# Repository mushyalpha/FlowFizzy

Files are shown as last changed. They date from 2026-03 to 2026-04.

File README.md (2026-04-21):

# FlowFizzy Water Dispenser

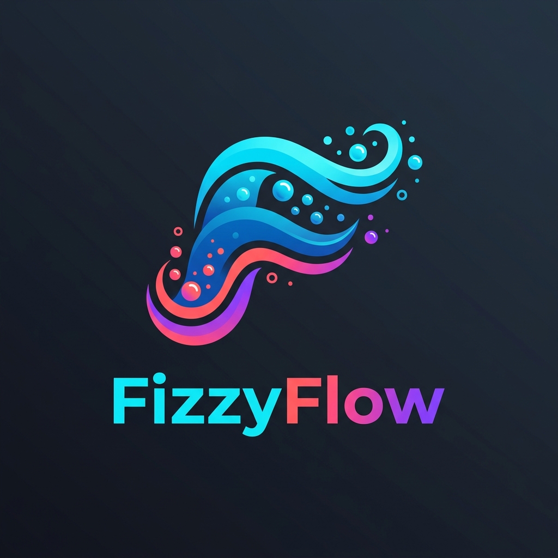
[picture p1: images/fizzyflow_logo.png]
FlowFizzy Logo


FlowFizzy is a smart, fully-automated touchless water dispenser built on the Raspberry Pi using C++. It utilizes intelligent hardware monitoring to safely dispense exact volumes of water using proximity detection.

For SOLID compliance, `FillingController` now depends on behavioral interfaces (`IProximitySensor`, `IPump`, `IFlowMeter`) instead of concrete drivers. We considered a template-based variant for zero-overhead static polymorphism, but chose runtime interfaces for clearer architecture and easier assessment traceability; at a 100 ms control interval, virtual dispatch overhead is negligible.

### [Watch the End-to-End Demo on YouTube](#) <!-- TODO: Add YT Link -->
### [Read our Project Tech Write-up on RS Design Spark](#) <!-- TODO: Add Blog Link -->
### [Follow us on Instagram](https://www.instagram.com/flow_fizzy/)

## Hardware Connections (Raspberry Pi Pinout)

Below is the definitive hardware wiring guide to connect the sensors and pump to the Raspberry Pi. For a visual representation, please refer to our physical circuit diagram:
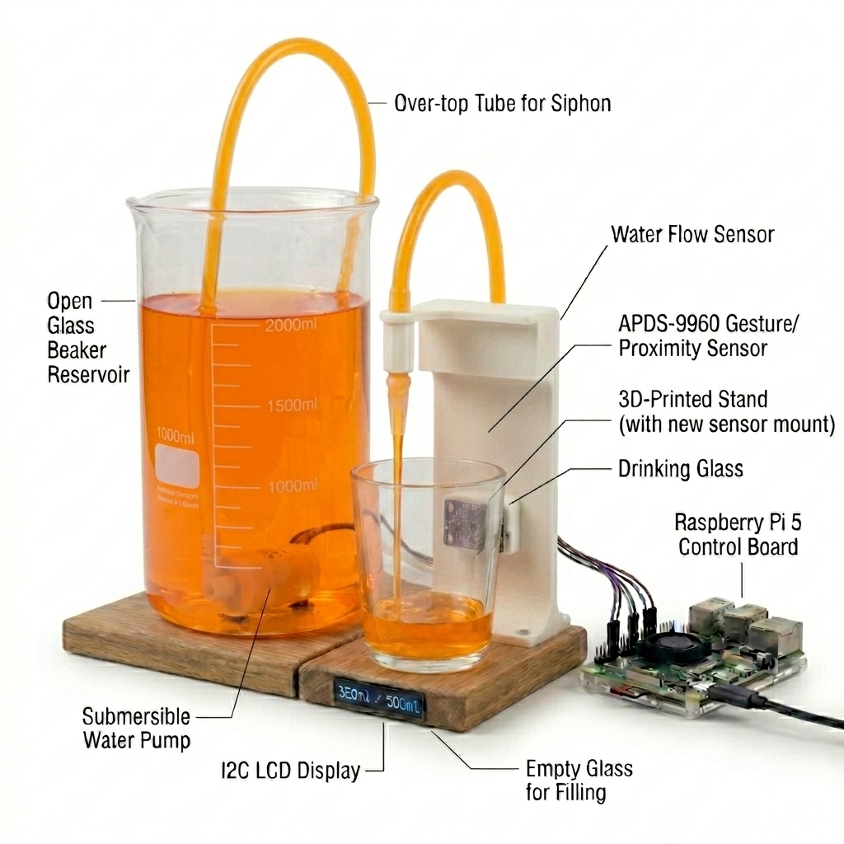
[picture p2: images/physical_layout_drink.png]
Drink Dispensing View


> **Note:** Always ensure the Raspberry Pi is powered OFF when altering hardware connections. 

### 1. Gesture/Proximity Sensor (DollaTek APDS-9960)
This acts as the touchless cup detector. It communicates via the I2C protocol natively over `3.3V`.
| Sensor Pin | Raspberry Pi Pin | Function |
| :--- | :--- | :--- |
| **VCC** | **Pin 1 (3.3V)** | Main Power |
| **GND** | **Pin 6 (GND)** | Ground |
| **SDA** | **Pin 3 (GPIO 2)** | I2C Data Line |
| **SCL** | **Pin 5 (GPIO 3)** | I2C Clock Line |
| **VL** | **Pin 17 (3.3V)** | Powers the IR LED for proximity |

### 2. Water Flow Sensor (YF-S401)
Sends digital pulses to precisely measure volume.
| Sensor Wire Color | Raspberry Pi Pin | Function |
| :--- | :--- | :--- |
| **Red** | **Pin 2 (5V)** | Power |
| **Black** | **Pin 9 (GND)** | Ground |
| **Yellow** | **Pin 11 (GPIO 17)** | Pulse Signal Line |

### 3. DC Submersible Pump (JT80SL via TIP122 Transistor)
Driven via a Darlington TIP122 with a flyback diode.
- **Base**: GPIO 18 (via 1k resistor)
- **Collector**: Pump Negative (-)
- **Emitter**: Ground (GND)
- **Diode**: Across Pump (+) and Collector.

---

## System Architecture

The system follows a strict event-driven, non-blocking architecture using `timerfd` and `libgpiod` interrupts. For full class and sequence diagrams, see our detailed [Architecture Documentation](docs/architecture.md).

```mermaid
graph TD
    A[Timer Worker] -->|timerfd 100ms| B[FillingController::tick]
    C[Gesture Worker] -->|timerfd 50ms| B
    D[Flow Worker] -->|GPIO Interrupt| E[Atomic Pulse Count]
    B -->|Atomic Read| E
    B -->|GPIO Write| F[Pump Controller]
    B -->|Callback| G[LCD Display]
```

### Real-Time Timing Requirements
| Requirement | Value | Mechanism |
| :--- | :--- | :--- |
| Gesture Poll Interval | 50 ms | `timerfd` (blocking) |
| State Machine Tick | 100 ms | `timerfd` (blocking) |
| Flow Interrupt Latency | < 1 ms | `libgpiod` Edge Events |
| Emergency Stop | < 150 ms | Proximity CLEARED → Pump OFF |

---

## Division of Labor
| Team Member | Primary Responsibilities |
| :--- | :--- |
| **Abdullah Alkabbawi** | Real-Time Architecture, State Machine Logic, Hardware Integration, Multithreading. |
| **Bonolo Masima** | Hardware Specifications, Documentation (ADRs), CAD Design, Integration Testing. |

---

## Bill of Materials (BoM)
| Item | Cost |
| :--- | :--- |
| DollaTek APDS-9960 Gesture Sensor | £4.99 |
| YF-S401 Water Flow Sensor | £7.45 |
| JT80SL DC Submersible Pump | £5.20 |
| TIP122 Transistor + Diode + Resistor Kit | £2.50 |
| 16x2 I2C LCD Display | £6.10 |
| Breadboard & Jumper Wires | £3.50 |
| Silicone Tubing (1m) | £2.00 |
| **TOTAL** | **£31.74 (Target: < £75)** |

---

## Build & Run Instructions

### 1. Fresh Raspberry Pi Installation
If you are starting from a completely blank Raspberry Pi OS (Bookworm or newer), follow these steps:
1. **Flash OS:** Flash Raspberry Pi OS (64-bit recommended) onto a MicroSD card using Raspberry Pi Imager. Ensure SSH and Wi-Fi are configured.
2. **Boot & Connect:** Insert the SD card, boot the Pi, and SSH into it.
3. **Enable I2C:** Run `sudo raspi-config` -> `Interfacing Options` -> `I2C` -> Enable.
4. **Clone the Repo:** `git clone https://github.com/mushyalpha/FlowFizzy.git && cd FlowFizzy`

### 2. Prerequisites
Run the following exactly as listed to install C++ compilers, CMake, and the standard GPIO driver library:
```bash
sudo apt-get update
sudo apt-get install -y cmake g++ libgpiod-dev libgpiod-doc
```

### 3. Build Instructions
```bash
mkdir build && cd build
cmake ..
make -j$(nproc)
```

### 4. Running Tests
You can automatically run all unit tests from the `build` directory:
```bash
# Run Google Test unit tests
make test
# OR manually run ctest to view verbose outputs:
ctest -V

# (Optional) Run hardware integration testing binaries:
sudo ./hardware_trio_test
```

### 5. Running the Application
```bash
sudo ./filling_machine
```

---

## Licensing
This project is licensed under the MIT License - see the [LICENSE](LICENSE) file for details.

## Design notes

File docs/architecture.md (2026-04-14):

# System Architecture

This document presents the overarching software design, sequence flows, and exact components mapping that define the AquaFlow touchless automated dispenser system.

---

## 1. Class Diagram

The following diagram demonstrates the core **SOLID** structural choices made for this system.
Note the heavy reliance on **Dependency Inversion (D)**: The `FillingController` acts only on abstractions (`IHardwareDevice` inputs mapped as concrete injected instances at run-time). It is completely unaware of Linux/GPIO specifics.

```mermaid
classDiagram
    class IHardwareDevice {
        <<interface>>
        +init() bool
        +shutdown() void
    }

    class FlowMeter {
        -atomic~int~ pulseCount_
        -thread edgeThread_
        +getPulseCount() int
        +getVolumeML() double
        +hasReachedTarget(double) bool
    }

    class PumpController {
        -bool running_
        -int pumpPin_
        +turnOn() void
        +turnOff() void
        +isRunning() bool
    }

    class GestureSensor {
        -int i2cAddr_
        -timerFd_
        +registerEventCallback(cb) void
    }

    class FillingController {
        -SystemState state_
        -double targetVolumeML_
        +tick() void
        +registerMonitor(cb) void
    }

    class Monitor {
        +onStateChange(string, double, int)
    }

    class LcdDisplay {
        +printStatus(string, double, int)
    }

    IHardwareDevice <|-- FlowMeter
    IHardwareDevice <|-- PumpController
    IHardwareDevice <|-- GestureSensor
    IHardwareDevice <|-- LcdDisplay
    
    FillingController --> GestureSensor : uses
    FillingController --> PumpController : uses
    FillingController --> FlowMeter : uses
    
    Monitor ..> FillingController : observer
    LcdDisplay ..> Monitor : bound callback
```

---

## 2. Sequence Diagram

This sequence traces the primary temporal flow of operations: From the user placing their cup, through proximity callbacks and flow counting, closing off back to an idle state.

```mermaid
sequenceDiagram
    actor User
    participant GS as Gesture Sensor (Thread)
    participant FC as FillingController
    participant T as Timer (Main Tick)
    participant P as PumpController
    participant FM as FlowMeter (Thread)
    participant L as LcdDisplay
    
    User->>GS: Place cup near sensor
    activate GS
    GS-->>FC: Proximity Triggered Event (Store Atomic=True)
    deactivate GS
    
    loop Every 100ms
        T->>FC: tick()
        FC->>FC: STATE: WAITING -> CONFIRMATION
    end
    
    note over FC,T: Cup held for Hold Time (e.g. 2s)
    
    T->>FC: tick() (hold time complete)
    FC->>FM: resetCount()
    FC->>P: turnOn()
    FC->>FC: STATE: CONFIRMATION -> FILLING
    FC-->>L: Update Dislay (Filling)
    
    loop Real-Time Flow Monitoring
        FM->>FM: Hardware Pulses increment Volume (Async)
        T->>FC: tick()
        FC->>FM: hasReachedTarget(volume) -> False
        FC-->>L: Update Volume Dispensed
    end
    
    note over FM: Target Volume Reached
    T->>FC: tick()
    FC->>FM: hasReachedTarget(volume) -> True
    FC->>P: turnOff()
    FC->>FC: STATE: FILLING -> FILL_COMPLETE
    FC-->>L: Update Display (Done)
    
    User->>GS: Removes Cup
    GS-->>FC: Proximity Cleared Event
    
    T->>FC: tick()
    FC->>FM: resetCount()
    FC->>FC: STATE: FILL_COMPLETE -> WAITING
```

---

## 3. Physical Software Mapping Architecture

This diagram demonstrates how hardware interfaces directly communicate natively with our encapsulated classes to form the whole package.

```mermaid
graph TD
    subgraph Physical Hardware
        APDS9960[APDS-9960 Gesture/Prox]
        YFS[YF-S401 Flow Meter]
        PumpEngine[JT80SL Pump + TIP122]
        LCD[16x2 I2C LCD Display]
    end

    subgraph Hardware Abstraction Layer
        GS_Class[GestureSensor]
        FM_Class[FlowMeter]
        Pump_Class[PumpController]
        LCD_Class[LcdDisplay]
    end

    subgraph OS Protocols
        I2C1[I2C Bus 1]
        GPIO_Edge[libgpiod Edge Events]
        GPIO_Out[libgpiod Digital Output]
    end

    APDS9960 -->|I2C 3.3v| I2C1
    I2C1 --> GS_Class

    YFS -->|Pulses 5v| GPIO_Edge
    GPIO_Edge --> FM_Class

    Pump_Class --> GPIO_Out
    GPIO_Out -->|Digital High 3.3v| PumpEngine

    LCD_Class --> I2C1
    I2C1 -->|Commands| LCD
```

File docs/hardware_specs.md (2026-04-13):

# Hardware Specifications

A reference document for the various hardware components used in the AquaFlow project.

---

## Pump: JT80SL DC Submersible Mini Water Pump
- **Electrical:**
  - Voltage: DC 2.5–6V
  - Current: 130–220 mA
  - Power: 0.4–1.5W
- **Performance:**
  - Flow rate: 80–120 L/H
  - Max head (hydraulic lift): 40–110 cm
- **Physical:**
  - Length: 56 mm (including water inlet)
  - Height: 33 mm (including water outlet)
  - Diameter: 24 mm
  - Weight: 30 g
  - Water inlet/outlet inner diameter: 4.5 mm (both)
  - Water inlet outer diameter: 6.8 mm
  - Water outlet outer diameter: 7 mm
- **Operating Notes:**
  - Submersible only - not self-priming; water level must be above the pump at all times.
  - Running dry causes overheating and noise.
  - Rotor can clog; clean regularly if water quality is low.

---

## Sensor: YF-S401 Hall Effect Water Flow Sensor
- **Electrical:**
  - Operating voltage: DC 5V–18V (datasheet min: 3.5V, practically works at 3.3V per field reports)
  - Max current draw: 15 mA (at DC 5V)
  - Signal output: Square wave pulse (Hall effect, open collector)
- **Performance:**
  - Flow range: 0.3–6 L/min
  - Pulse rate: ~5880 pulses/litre (~0.17 mL per pulse)
  - Max water pressure: 1.75 MPa
- **Physical:**
  - Dimensions: 58 × 35 × 27 mm
  - Weight: 25 g
  - Connection: G1/4" fitting, compatible with 5–7 mm ID hose (6 mm optimal)
  - Included: 30 cm silicone tubing (6 mm ID)
- **Wiring (3-wire):**
  - Red: VCC (5V)
  - Black: GND
  - Yellow: Signal (pulse output)
- **Operating Notes:**
  - Hall effect sensor is sealed from the water path - stays dry.
  - Not self-priming; designed for inline use in an active flow path.
  - Clean water only; avoid chemical exposure and physical shock.

---

## Gesture Sensor: DollaTek APDS-9960
- **Features:** Sensor for ambient light, RGB detection, proximity, gesture, and motion recognition.
- **Brand:** DollaTek
- **Power:** Corded Electric; operates at 3.3 V 
- **Weight:** 0.08 kg
- **Interaction:**
  - Detects ambient light and RGB colors accurately.
  - Recognizes gestures: Up, Down, Left, Right.
  - Detection range: 100–200mm. 
- **Hardware Integration:**
  - Communicates via I2C interface.
  - Features infrared LED, proximity sensor.
  - Pins: VCC/GND (3.3 V power), SDA/SCL (I2C), INT (interrupt), VL (infrared LED power).
  - Board size: 15.5 x 20.5 mm.

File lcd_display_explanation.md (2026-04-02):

# LcdDisplay Code Explanation

This document explains the functionality of the `LcdDisplay` component in the AquaFlow project, specifically focusing on `LcdDisplay.h` and `LcdDisplay.cpp`.

## Overview
The `LcdDisplay` class is a hardware driver for a **Freenove I2C LCD 1602** display (16 columns, 2 rows). It controls an underlying HD44780 LCD controller attached via a PCF8574T I2C backpack. This setup allows the Raspberry Pi to control the full display using only **4 wires** (5V power, Ground, SDA data, and SCK clock) over the I2C interface.

The class implements the `IHardwareDevice` interface, ensuring it integrates cleanly and identically to other hardware components in the system like the `PumpController` and `FlowMeter`.

## Key Features

1. **Direct POSIX I2C Communication**: 
   The code uses the standard Linux kernel I2C interface (`/dev/i2c-N` and `ioctl()`) to communicate directly with the device. This is a very clean approach because it avoids pulling in bulky third-party libraries (like WiringPi), relying entirely on standard C++ POSIX functions.

2. **Flicker-Free Text Updating**: 
   A common issue with basic LCD code is that clearing the screen before printing new text causes a visible, annoying "flicker". This driver solves that in the `print()` method by intelligently padding every string with spaces so it is exactly 16 characters long. This perfectly overwrites the previous text without ever needing to clear the screen!

## Core Methods

### `init()`
- Opens the `/dev/i2c-N` file corresponding to the configured bus number to establish the connection.
- Executes the highly specific initialization sequence required by the HD44780 datasheet: sending pulses and waiting exact microsecond delays to put the display into "4-bit mode".
- Configures the display for 2 lines and 5x8 dot characters.
- Turns on the display, turns on the backlight, clears the screen, and sets the cursor to automatically advance to the right.

### `shutdown()`
- Safely and cleanly powers down the display.
- Clears the screen and prints a farewell message: `AquaFlow \ Shutting down...`.
- Waits 1.5 seconds so the user can read the message, then dynamically cuts power to the backlight and closes the Linux file descriptor.

### `print(int row, const std::string& text)`
- Utility method to write text to either the top row (`0`) or bottom row (`1`).
- Manipulates the string to be precisely 16 characters long.

### `showVolume(double volumeML)`
- Formats the current dispensed liquid volume into a readable string (e.g., `Vol: 123.4 ml`).
- Specifically updates the bottom row (row 1). This is meant to be called rapidly (e.g. 1Hz timer) while the machine is actively filling a bottle.

### `showStatus(const std::string& state, double volumeML, int bottles)`
- High-level method called by the main system whenever the machine changes states (e.g., from `IDLE` to `FILLING`).
- **Row 0**: Writes the current system state (e.g. `FILLING`). It has a smart optimization where it skips writing if the state hasn't changed, saving processing and I2C bandwidth!
- **Row 1**: Contextually decides what to show. If it's `FILLING`, it shows the live volume. If the machine is resting (`IDLE`, `DONE`, `WAITING`), it displays the total count of bottles dispensed so far.

## Low-Level Hardware Interface (The bottom half)
The bottom portion of the code (`send`, `write4bits`, `pulseEnable`, etc.) handles the grueling electronics protocol required for the backpack chip:
- Because the I2C chip only has 8 pins, and the LCD requires more, the driver uses "4-bit mode". It splits every byte of data into two 4-bit chunks ("nibbles") and sends them one after the other.
- The `pulseEnable()` function accurately toggles the LCD's `En` (Enable) pin HIGH then LOW in the span of exactly 51 microseconds, effectively telling the chip "LATCH THIS DATA NOW".
- The `expanderWrite()` function always intelligently ORs your data with the backlight bit. This ensures that every time you send data, the code doesn't accidentally turn off the backlight.

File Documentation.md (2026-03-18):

# Smart Flow - Automated Water Dispenser

**Components:** Water Pump | YF-S401 Flow Meter | HC-SR04 Ultrasonic Sensor

---

| Field | Details |
| --- | --- |
| **Project Title**  | Smart Flow - Automated Water Dispenser |
| **Platform** | Raspberry Pi 5 using C++ |
| **Core Mechanism** | Manual bottle placement → detect & stabilise → fill to target → remove |
| **Key Sensors** | YF-S401 flow meter + HC-SR04 ultrasonic sensor |
| **Control Logic**  | Real time state machine (20ms loop) |

---

## 1. Summary

This project implements a real time Automated Water Dispenser on a Raspberry Pi 5 using C++. The system detects when a user places a bottle or a glass under the nozzle using an ultrasonic sensor, waits for the reading to stabilise (to ignore passing hands), fills the bottle to a precise target volume using a flow meter, and stops. The entire process is controlled by a hard real-time state machine running at a 20ms loop.

> **Hard real-time consequence of missing a deadline:** At a flow rate of ~400 ml/min, the pump dispenses ~6.6 ml/sec. If the pump-stop ISR is delayed by more than 5 ms, the bottle or glass overfills.

---

## 2. Problem Statement

Manual water bottling is slow and inconsistent in fill volume. This project demonstrates how an automated water dispenser can be built using an affordable single board computer and real-time C++, achieving high fill accuracy.

The core engineering challenges are:
1. Detecting a bottle or glass reliably with an ultrasonic sensor, filtering out spurious signals (like a hand moving past).
2. Monitoring the rising water surface with the same ultrasonic sensor to stop filling before the glass overflows.
3. Measuring dispensed volume accurately using pulse counting from a flow meter.
4. Ensuring the pump stops at exactly the right moment to hit the target volume.
5. Coordinating the sensors and pump as a single real-time system with no timing errors.

### The Complete Filling Cycle

| Step | Action |
| ---- | --- |
| **Step 1: IDLE** | System waiting, pump off. |
| **Step 2: DETECTED**  | Ultrasonic sensor detects object at correct distance. |
| **Step 3: STABILISE** | System waits briefly to confirm it is a bottle, not a hand. |
| **Step 4: FILLING** | Pump on, flow meter counting pulses. |
| **Step 5: COMPLETE**  | Ultrasonic detects water surface near top, or pulse count hits target. Pump stops. |
| **Step 6: REMOVE** | User removes filled bottle. System returns to Step 1. |

---

## 3. System Architecture

### 3.1 Physical Layout

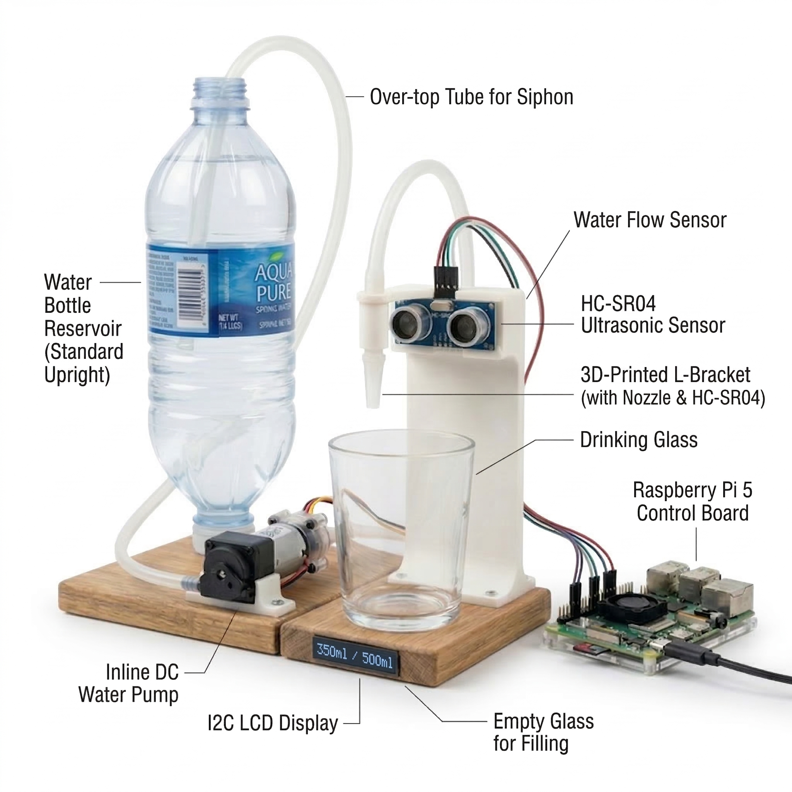
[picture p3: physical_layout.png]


### 3.2 State Machine Diagram

```mermaid
stateDiagram-v2
    [*] --> IDLE
    IDLE --> STABILISING : bottle or glass detected
    STABILIZING --> FILLING : Stable for a few ms
    
    state FILLING {
        [*] --> Pump_ON
        Pump_ON --> Read_Flow_Sensor
        Read_Flow_Sensor --> Update_LCD
        Update_LCD --> Read_Flow_Sensor : Loop while filling
    }
    
    FILLING --> FILL_COMPLETE : Flow >= Target
    FILL_COMPLETE --> IDLE : Bottle Removed
```

---

## 4. Software Architecture: Class Design (SOLID Principles)

All Raspberry Pi code is written in C++ following SOLID design principles. Each hardware component is contained in its own class with a well defined public interface. All internal data is private, and classes communicate exclusively through callbacks and setters, never through shared global state. Dynamic resources are managed via RAII and `std::shared_ptr`; there are no raw `new`/`delete` calls or void pointers in application code.

| Class | Responsibility |
| --- | --- |
| `WaterPump` | Wraps relay GPIO; controls pump power via `on()`/`off()` setters |
| `FlowMeter` | Owns pulse ISR thread; converts pulses to ml; exposes `std::function` callback on each pulse |
| `UltrasonicSensor` | Manages trigger/echo pins; measures distance to bottle and rising water surface; exposes callback with distance reading |
| `FillingStateMachine` | Orchestrates state transitions; subscribes to sensor callbacks; calls pump setters |
| `MonitorThread` | Normal-priority thread: LCD, MQTT, CSV log |

### 4.1 Event-Driven Callback Flow

The system is fully event-driven following the blocking I/O + thread wakeup pattern taught in the course. There are no polling loops or sleep based timing anywhere in the application.

---

---

**How each thread works:**

1. **FlowMeter thread** (priority 90): uses `libgpiod` `wait_edge_events()` as blocking I/O. The thread sleeps until a rising edge arrives from the YF-S401 Hall sensor, then increments the pulse counter and fires the callback. No CPU is consumed while waiting.
2. **UltrasonicSensor thread** (priority 80): triggers a 10us pulse on the trigger pin, then blocks on the echo pin edge event via `libgpiod`. The time between rising and falling edge gives distance. Fires callback with the result.
3. **FillingStateMachine** (priority 80): runs on a 20ms periodic loop using `clock_nanosleep`. Each iteration reads the latest sensor values delivered by callbacks and evaluates state transitions.
4. **MonitorThread** (normal priority): a non-real-time thread that updates the LCD, publishes MQTT telemetry, and writes CSV logs. It is never in the critical path.
5. **Main program**: after constructing all objects and registering callbacks via lambda functions, the main thread blocks (e.g. `getchar()`) and does no further work until shutdown.

---

## 5. Real-Time Latency Budget

All timing decisions are derived from measured or calculated worst-case latencies.

| Event | Latency Target | Consequence of Miss | Mechanism |
| --- | --- | --- | --- |
| Flow meter pulse ISR response | < 1 ms | Pulse lost, volume miscounted | `SCHED_FIFO` 90 ISR thread (highest priority) |
| Pump stop at target volume | < 2 ms | Overfill by ~16 ml per ms of delay | ISR directly writes GPIO via `stop()` |
| LCD / MQTT update | < 500 ms | No user-visible impact | Normal-priority `MonitorThread` (non-RT) |
| State machine loop period | 20 ms | Delayed response to sensor events  | `SCHED_FIFO`, `clock_nanosleep` periodic wake |

**Why `SCHED_FIFO` priority 80?** This places the control loop above standard Linux processes (priority 0 to 20) while reserving priority 99 for kernel interrupt threads and priority 90 for the pulse ISR, ensuring the flow meter ISR always pre-empts the state machine rather than the reverse.

---

## 6. GUI and Data Visualisation

A Qt 6 GUI runs on the Raspberry Pi and provides real-time plotting of the dispensing process. The GUI is refreshed via a Qt timer (screen refresh only, not used for real-time timing) while actual sensor data arrives through the callback architecture described above.

| Widget | Purpose |
| --- | --- |
| QCustomPlot graph | Live plot of flow rate (ml/s) and fill level over time |
| Volume label | Current dispensed volume in ml |
| Target spinbox | Allows the user to set a custom fill target via mouse/keyboard |
| Reset button | Clears the current fill and returns to IDLE |

The GUI thread is started last in `main()` with `app.exec()`, which blocks. All real-time threads are started before the GUI. Qt timers are used only for screen refresh (~40 ms interval) and are never used for sensor timing.

**Prerequisites for GUI:**

```
sudo apt-get install qt6-base-dev libqcustomplot-dev
```

---

## 7. Hardware Components

| Component | Purpose |
| --- | --- |
| Raspberry Pi 5 | Main real-time controller |
| 12V Water Pump | Drives water flow from tank to nozzle |
| 5V 1-Channel Relay (Opto-isolated) | Switches the 12V pump on and off via GPIO |
| YF-S401 Flow Meter | Measures fill volume in ml (low flow) |
| HC-SR04 Ultrasonic Sensor + Clamp  | Detects bottle presence and monitors rising water level |
| 16x2 LCD (I2C) | State and fill volume display |
| Active Buzzer | Fill complete audio feedback |
| 1N4007 Diode | Flyback protection on pump relay |

---

## 8. Build and Run

### Prerequisites

```bash
sudo apt-get install cmake g++ libgpiod-dev qt6-base-dev libqcustomplot-dev libi2c-dev
```

### Build

```bash
cmake .
make
```

### Run

```bash
sudo ./smart_flow
```

`sudo` is required for GPIO access and `SCHED_FIFO` thread scheduling.

### Unit Tests

```bash
make test
```

Unit tests verify:
- Flow meter pulse-to-ml conversion accuracy
- Ultrasonic sensor distance calculation
- State machine transitions (IDLE to STABILISE to FILLING to COMPLETE)
- Pump GPIO on/off sequencing

---

## 9. Division of Labour

| Member | Primary Responsibility |
| --- | --- |
| Chandan and Radha | Hardware assembly: mechanical build, wiring, hardware sourcing |
| Bonolo and Abody  | Real time software: state machine, ISR handlers, SCHED_FIFO threading |
| Bonolo, Abody, Radha | Sensor integration: flow meter calibration, ultrasonic sensor tuning |
| Mena | Monitoring and data: LCD driver, MQTT dashboard, CSV logging |
| Mena and Radha | Testing, documentation and presentation: unit tests, GitHub Pages |

---

## 10. License

This project is licensed under the MIT License.

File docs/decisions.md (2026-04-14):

# Architecture & Technical Decisions (ADRs)

A master log of technical bottlenecks and the resolutions implemented for the AquaFlow project.

---

## [CLOSED] Decision 1: Pump vs Solenoid Valve
- **Problem:** The original setup utilised a 12V Solenoid valve. It looked solid and we bought a relay for it, but ultimately we couldn't get it working with our setup and it made the footprint too bulky.
- **Resolution:** Reverted to a DC submersible pump (JT80SL) instead of the solenoid valve.

## Decision 2: Managing Pump Power Draw
- **Problem:** The JT80SL draws up to 220mA, which is > 10x what a single Raspberry Pi GPIO pin can safely handle (16 mA max). 
- **Resolution:** We cannot connect it directly. Instead of using 3x 1.5v AA batteries, we wired a **T1P121 transistor with a flyback diode and a 1000 ohm resistor**. (Note: Consider switching to a MOSFET in the future).
- *Open Concern:* We need to establish if the concern about the 5V pin being over-occupied is a real concern and how to solve it.

## Decision 3: Resolving 5V Rail Contention
- **Problem:** We have 2 sensors, a pump, and LCDs, and they are all competing for the Pi's 5V rail. We used a relay module for the pump that took up two 5V pins.
- **Resolution Plan:** The pump should ideally be powered from a separate 5V supply rather than directly from the Pi. This avoids startup current spikes that can drop voltage and destabilise the Pi. Pi GPIO should only be used for control.
- **Proposed setup:** 
  - External 5V supply for pump.
  - Relay or MOSFET for switching.
  - Common ground shared with Raspberry Pi.
  *(Note: We already have a 12V power supply and can use an LM2596 Buck Converter).*

## Decision 10: Fluid Dynamics & Tubing Layout

- **Context:** We have 1m of 6mm tubing and need to determine the optimal configuration for connecting the submersible pump, the YF-S401 water flow sensor, and the dispensing nozzle.
- **Decision:** **Use the shortest possible tubing run. The pump must be submerged, with the flow sensor placed inline after the pump.**
- **Rationale for Tubing Length (Shorter is Better):**
  - **Priming Latency:** A longer tube holds more air when empty, causing a noticeable delay before water reaches the cup when the pump starts. Shorter tubes mean a snappier, more responsive system.
  - **Head Loss:** Longer tubes create more flow friction, putting unnecessary strain on our small 5V DC pump and reducing the maximum flow rate.
  - **After-Drip:** A long tube acts as a reservoir. Once the pump cuts off, any water remaining in the tube will slowly drip out, which completely ruins the precision of our calibrated dispensing volumes.
- **Rationale for Component Positioning:**
  - **Pump Submersion:** The JT80SL is a *submersible* pump. Because it draws water through a slotted casing rather than an inlet port, there is no way around it: it **must** sit fully submerged at the bottom of the water source/reservoir.
  - **Flow Sensor Placement:** The flow sensor must be placed on the pressure-side (attached directly to the tubing coming *out* of the pump). It requires positive, pressurized flow to spin its internal hall-effect turbine accurately. 
  - **Proximity:** Keep the flow sensor relatively close to the pump but try to allow a straight run of tubing leading into it. Minimizing curves right before the sensor reduces turbulent water flow, leading to much more stable and predictable pulse readings.

---

## Decision 4: Hardware Scope - Keep Current Design, Do Not Expand

- **Context:** Proposal raised to extend the hardware (viscosity sensing, restoring the ultrasonic sensor). The counter-argument is that expanding hardware scope at this stage risks diverting time away from code quality - the primary marking criterion.
- **Decision:** **Freeze the hardware at its current scope.** The system already fulfils its core function (touchless cup detection → pump → precise volume dispensing) and does so well. Adding components for novelty at this stage would provide diminishing returns.
- **Rationale:**
  - The assessment is marked predominantly on code quality (SOLID, encapsulation, real-time architecture, revision control, documentation). Hardware is not a graded criterion on its own.
  - The novelty angle was assessed at the presentation stage, which has already passed.
  - Bringing back the ultrasonic sensor is redundant - the APDS-9960 gesture sensor handles proximity detection and is already integrated. Running both in parallel would add complexity with no functional benefit.
  - Time is better invested in: unit tests, documentation, UML diagrams, and commit quality - all of which directly affect the final grade.

---

## Decision 5: Pump Power Supply - Evaluate Powerbank Integration

- **Context:** Current setup drives the pump via a TIP122 transistor + flyback diode from the Pi's 5V rail. A portable powerbank is available that could act as a dedicated external supply.
- **Decision:** **Conditionally adopt the powerbank if integration is non-invasive.** If it can be wired as a simple external 5V supply (common ground with Pi, pump powered via powerbank, transistor control signal still from GPIO) without requiring a redesign of the existing circuit, it is worth adopting.
- **Rationale:**
  - A dedicated supply eliminates current spikes on the Pi's 5V rail, reducing the risk of the Pi browning out mid-dispense.
  - The transistor switching circuit (base resistor + flyback diode) remains unchanged - only the supply rail moves.
  - If it requires more than 30 minutes of hardware rework, defer. Code quality is the priority.
- **Open action:** Wire powerbank → collector side of TIP122; verify common ground with Pi. Test pump performance under load.

---

## Decision 6: Volume Measurement - Retain Flow Meter, Improve Calibration

- **Context:** Proposal to replace the YF-S401 flow meter with a load cell for more accurate volume measurement. The flow meter required field calibration against a beaker.
- **Decision:** **Retain the YF-S401 flow meter.** Recalibrate using a more accurate volumetric flask if precision is still insufficient.
- **Rationale:**
  - Replacing the flow meter with a load cell would require a new hardware driver class, new calibration, and re-integration with `FillingController` - a significant diversion of time.
  - The flow meter's event-driven pulse counting is already a strong RTES demonstration (GPIO interrupt → `atomic<int>` → callback). A load cell would likely require polling an ADC, which is architecturally weaker for this course.
  - The current calibration (`0.073774 ml/pulse`, derived from 2711 pulses for 200 ml) is documented and reproducible. A more accurate flask would tighten this without touching code.
  - A load cell is only justified if the flow meter's accuracy is proven to be a functional problem during the demo. Until then, it is not worth the risk.

---

## Decision 7: Gesture Sensor - Improve C++ Implementation, Do Not Switch Libraries

- **Context:** Gesture direction detection (swipe UP/DOWN/LEFT/RIGHT) works reliably in Python but produces unreliable results in C++. Proximity detection works well in both. Proposal raised to port the Python library logic to C++.
- **Decision:** **Improve the existing C++ FIFO parsing implementation.** The full APDS-9960 register-level documentation is available; the Python library is open-source and can be used as a reference for the algorithm, not as a dependency.
- **Rationale:**
  - The Python library (e.g., `adafruit-circuitpython-apds9960`) is not a C++ dependency and cannot be called directly. "Converting" it means reading its gesture-decoding logic and reimplementing it in C++ - which is exactly what our current `GestureSensor.cpp` does.
  - The likely cause of the discrepancy is the FIFO read timing. Python libraries typically add small delays between FIFO reads to allow the gesture engine to settle; our C++ implementation polls the FIFO on a 50 ms timerfd tick which may be too coarse or too fast for certain swipe speeds.
  - **Fix approach:** Compare the Python library's gesture-decoding thresholds and FIFO drain strategy against our current implementation. Tune `POLL_INTERVAL_MS`, gesture entry/exit thresholds (`GPENTH`/`GEXTH`), and the minimum-frame filter (`gesture_dataset_count_ > 4`).
  - If gestures are improved, this becomes a strong novelty differentiator for the demo. If they remain unreliable, proximity-only mode (cup detection) is sufficient for the core dispensing function.
- **On the ultrasonic sensor suggestion:** Rejected. An ultrasonic sensor cannot detect gesture direction and would only replicate the proximity function already handled by the APDS-9960.

---

## Decision 8: Project Complexity - Sufficient for Assessment Purposes

- **Context:** Concern raised that the project may be too simple from a hardware perspective relative to other teams.
- **Decision:** **Scope is adequate; shift focus to code depth and documentation quality.**
- **Rationale:**
  - Complexity in this course is judged on the *code*, not the number of hardware components. A simple hardware setup with excellent SOLID architecture, event-driven threading, comprehensive unit tests, and clean documentation will outperform a complex hardware setup with poor code quality.
  - AquaFlow already demonstrates: multi-threaded event-driven architecture (`GestureSensor` + `FlowMeter` + `Timer` each on independent worker threads), a proper state machine (`FillingController`), RAII memory management, and `libgpiod` v2 GPIO - all of which are exactly what the marking rubric rewards.
  - If gesture detection is polished and working for the demo, that alone is a compelling novelty angle that requires no additional hardware.

---

## Decision 9: Final Form Factor - Prototype HAT / Stripboard vs Custom PCB

- **Context:** The current breadboard prototype is messy with loose wires. A proposal was made to design and order a custom PCB for a cleaner final product. However, there is concern about the time investment required.
- **Decision:** **Migrate to a solderable Stripboard or Raspberry Pi Prototype HAT instead of a custom PCB.**
- **Rationale:**
  - Standard PCB fabrication and shipping lead times (e.g., JLCPCB) take 1-2 weeks, which introduces massive timeline risk if the board is delayed or requires a second revision.
  - Designing a PCB in KiCad diverts significant time away from code architecture, testing, and documentation - all of which carry heavy weight in the assessment marking criteria.
  - A simple perfboard, stripboard, or Pi Prototype HAT achieves the exact same goal (eliminating loose breadboard jumper wires, creating a robust physical unit for demo day) but can be soldered together in a single afternoon using standard lab equipment.
  - The circuit is incredibly simple (one TIP122, a diode, a single resistor, and standard female header pins for the sensors) making a full custom PCB functionally overkill.

---

## Decision 11: Route Hardware Output through Logger (SRP Enforcement)

- **Context:** The `PumpController` class used explicit `std::cout` and `std::cerr` calls for debugging and status updates (e.g., pump initialization, start/stop events).
- **Decision:** **Substitute `std::cout/cerr` with `Logger::info()/error()` within all hardware driver classes (starting with `PumpController`).**
- **Rationale:**
  - **Single Responsibility Principle (SRP):** A hardware driver class should purely manage the hardware (e.g., pulling a GPIO pin high/low). Handling user presentation, including console output formatting, violates SRP because it gives the class two reasons to change: 1) if the hardware swaps, or 2) if logging/UI needs alteration.
  - By routing messages through the `Logger` component, `PumpController` delegates the responsibility of formatting, routing, and thread-safety of logs back to a centralized utility designed for that purpose.

---

## Decision 12: Architectural Principles & Multithreading (SOLID)

- **Context:** Deciding the software constraints and architecture map mapping logic state to hardware feedback.
- **Decision:** **Strictly enforce SOLID principles specifically Dependency Inversion (D), Liskov Substitution (L), and Open-Closed Principle (O) alongside an asynchronous event-driven layout.**
- **Rationale & Applied Implementations:**
  1. **Dependency Inversion + Liskov Substitution:** The state machine (`FillingController`) accesses hardware strictly through the abstract `IHardwareDevice` interfaces. This abstraction means we can freely swap real `PumpController` nodes with testing stub mocks dynamically without altering the controller's logic (Polymorphism).
  2. **Open-Closed Principle:** Display outputs are decoupled entirely via asynchronous **Observer Callbacks**. Instead of hardcoding `LcdDisplay` into the root controller, the controller simply broadcasts events (`onStateChange`) via the generic `Monitor` callback structure. This allows UI layers to alter significantly (Open for extension) without ever touching core logic (Closed for modification).
  3. **Event-Driven Threading Tradeoffs:** Rather than globally busy-polling GPIO ports (which uses 100% CPU latency overheads), `libgpiod` Edge Event workers and `sys/timerfd.h` were bound to isolate independent threads. The tradeoff is memory complexity with explicit thread execution tracking (`std::atomic<bool> pulseCount_`), but the system gains robust real-time sub-millisecond execution matching the stringent A1 criteria.

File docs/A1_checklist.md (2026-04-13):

# AquaFlow - A1 Grade Checklist
> Derived directly from the professor's marking criteria lecture.
> Each item maps to a specific graded criterion. **All boxes must be checked for A1.**

---

## 1. Code Structure - SOLID Principles

> Professor: *"A is really that you have thought through this, understood the right choices, and applied these professionally."*
> Global variables, no SOLID evidence → D/E. No evidence at all → F.

### S - Single Responsibility Principle
- [ ] **Every class has exactly ONE clearly-defined responsibility.** No "god classes" doing multiple jobs (e.g., a class that both reads the sensor AND controls the pump AND logs simultaneously).
- [ ] **Confirm current classes are properly separated:** `GestureSensor`, `PumpController`, `FlowMeter`, `LcdDisplay`, `FillingController`, `Monitor`, `Timer`, `Logger` - each should own one concern only.
- [ ] **Document in README/docs** which responsibility each class owns (justifies SRP compliance to the marker).

### O - Open/Closed Principle
- [ ] **Base classes exist that can be extended without modification.** e.g., `IHardwareDevice` as the base - new sensors should be addable by inheritance, not by editing existing classes.
- [ ] **Check `IHardwareDevice.h`** - does it provide a solid enough base that `FlowMeter`, `PumpController` etc. inherit from it without modifying the base?
- [ ] **Use inheritance + virtual functions** to add functionality (e.g., a future `4-channel ADC` class extends a base `ADC` class).
- [ ] **Document your inheritance hierarchy** - show it in a UML diagram.

### L - Liskov Substitution Principle
- [ ] **Base class interfaces are future-proof.** If you swap a derived class for the base class, nothing breaks.
- [ ] **Specifically: callbacks/interfaces in base classes must be flexible enough** to accommodate future derived classes (e.g., use `std::vector<float>` instead of a single `float` in callbacks so multi-channel readings don't break the interface).
- [ ] **Check `IHardwareDevice.h`** - if it declares a `getData()` callback with a fixed return type, verify the derived classes don't break substitutability.
- [ ] **Document in code comments/docs** your reasoning on Liskov compliance or why you consciously relaxed it.

### I - Interface Segregation Principle
- [ ] **No bloated interfaces.** Each class/callback interface exposes ONLY what the consumer needs - not a massive omnibus interface.
- [ ] **Sensor-specific callbacks are separate** - e.g., a flow reading callback is distinct from a gesture event callback; they're not crammed into one generic handler.
- [ ] **Verify** that no single class is being used as a catch-all for unrelated data.

### D - Dependency Inversion Principle
- [ ] **Decision documented:** Professor explicitly said DIP is hard in C++ and is optional - but your **choice must be documented** (in README/docs) explaining why you did or didn't apply it.
- [ ] **(Optional, high marks):** If attempting DIP, use C++ templates to decouple high-level logic from low-level hardware drivers so either can be swapped independently.
- [ ] **At minimum:** ensure high-level modules (`FillingController`) depend on **abstractions** (`IHardwareDevice`), not concrete classes directly.

---

## 2. Encapsulation

> Professor: *"A = clearly defined public interface, all variables in private, access only via getters/setters/callbacks, efficient internal data structures."*
> Global variables → D/E instantly. Everything dumped in `main` → F.

- [ ] **Zero global variables.** Do a full search across all `.cpp` and `.h` files. Any global mutable state is an immediate D/E.
- [ ] **All member variables are `private`** (or `protected` where justified). No `public` data members.
- [ ] **All data access is through getters, setters, or callbacks only.** No direct member access from outside the class.
- [ ] **Internal data structures are efficient** - e.g., consider using `std::atomic` for shared sensor readings, ring buffers or double-buffering for high-frequency data.
- [ ] **`main.cpp` contains only initialisation code** - no real-time logic, no loops, no processing. After init, it simply blocks on `sigwait()`.
  -  **Current state:** `main.cpp` already does this correctly with `sigwait()` - confirm it stays this way.
- [ ] **All callbacks are transmitted through `std::function` or abstract interface** - not via raw global function pointers.
- [ ] **Safe data receiving and releasing** - verify fault-checking mechanisms are in place when sensors disconnect or provide erroneous data.

---

## 3. Memory Management

> Professor: *"Use STL. Use smart pointers. Never void pointers. Never malloc. Prefer copy constructors."*
> `void*` or `malloc` = "deal-breaker" for this criterion.

- [ ] **No raw `new`/`delete` unless absolutely required** (e.g., Qt forces it). Use RAII.
- [ ] **No `malloc`/`free` anywhere in the codebase.** Run a search.
- [ ] **No `void*` pointers anywhere.** Run a search.
- [ ] **Use `std::shared_ptr` / `std::unique_ptr`** for any dynamically allocated objects.
- [ ] **Prefer copy constructors / value semantics** - assign objects directly (e.g., `std::thread thr = std::thread(...)`) instead of heap allocation.
- [ ] **Use STL containers** (`std::vector`, `std::queue`, `std::deque`) instead of C-style arrays where possible.
- [ ] **Review Rule of 3 / Rule of 5** - if any class manages a resource (thread, file handle, socket), ensure copy constructor, copy assignment, and destructor are properly defined (or explicitly deleted).
- [ ] **No memory leaks** - verify all threads are joined, all connections closed, all resources released in `shutdown()` methods.

---

## 4. Real-Time Coding

> Professor: *"This is the most important thing - and the easiest way to get marks."*
> Arduino-style polling loops, `sleep()`-based timing, or a frozen UI = automatic fail for this criterion.

### 4a. Timing Requirements - DOCUMENT THIS (easy marks, often missed!)
- [ ] **State your system's timing requirements explicitly in the README or docs.** e.g.:
  - *"The pump must respond to a cup-detected event within 50 ms of a proximity event."*
  - *"The flow meter samples at interrupt-driven rate; callback must complete in < 10 ms."*
  - *"The GestureSensor polls the APDS-9960 FIFO every 50 ms via timerfd."*
  - *"The state-machine tick fires every 100 ms via timerfd."*
  - Professor says ~30% of teams miss this and "earn a straight fail for it" - **do not skip**.

### 4b. Event-Driven, Non-Blocking Architecture
- [ ] **No polling loops.** No `while(true) { check_sensor(); sleep(100ms); }` patterns.
- [ ] **All I/O is event-driven:** threads block on a hardware event (GPIO interrupt, timerfd, I2C data-ready pin) and wake up only when data arrives.
- [ ] **`Timer` class uses `timerfd`** (or equivalent blocking mechanism) - not a `sleep()` loop.
  -  **Current state:** `main.cpp` uses `loopTimer.registerCallback()` - confirm `Timer` internally uses `timerfd` or `std::condition_variable`, not `sleep()`.
- [ ] **`FlowMeter` uses GPIO interrupt** on the pulse pin - not polling.
- [x] **`GestureSensor` uses `timerfd` blocking read** - replaced `sleep_for(50ms)` polling with a kernel-managed timerfd. Zero CPU between firings. ✅ Done.
- [ ] **No `sleep()` or `usleep()` used to establish timing.** These are unreliable on Linux (multitasking OS). Search the codebase.

### 4c. Fast & Deterministic Callbacks
- [ ] **Callbacks in sensor drivers are fast and deterministic.** No heavy computation, no I/O, no blocking calls inside a callback.
- [ ] **Slow/unpredictable work (e.g., any processing logic) is offloaded** to a separate `std::thread` - the callback just queues the data and returns.
- [ ] **`FillingController::tick()`** (called from timer callback) must be deterministic - no unbounded loops or I/O inside it.

### 4d. Thread Architecture
- [ ] **Each blocking I/O operation runs in its own dedicated worker thread:**
  - `Timer` worker thread (timerfd → `FillingController::tick()` callback)
  - `FlowMeter` worker thread (GPIO interrupt → pulse count, `atomic<int>`)
  - `GestureSensor` worker thread (timerfd → I2C FIFO read → proximity callback → `atomic<bool>` in `FillingController`)
- [ ] **`main()` thread only sleeps** (via `sigwait`) - it does not participate in any real-time processing.
- [ ] **Thread-safe data sharing** - use `std::atomic` or `std::mutex`+`std::lock_guard` for any data accessed from multiple threads.
- [ ] **No dead locks** - verify no two mutexes are locked in opposite orders in different threads.

---

## 5. Revision Control & Project Management

> Professor: *"Last-minute single upload = very low marks. Only one person committing = visible, penalised."*

### 5a. Git Commit & Release Quality
- [ ] **GitHub Release created by the deadline** - the professor will download and mark the latest *release*, not just the latest pushed commit. Don't forget to cut a tag/release!
- [ ] **Every commit has a descriptive message** - not "updated file", "fix", or "changes". Each message should explain WHAT was changed and WHY.
- [ ] **Commits reference issues where applicable** - e.g., "Fixed flow meter callback race condition (closes #12)".
- [ ] **Use git from the command line** (not just GUI drag-and-drop) to ensure full, detailed commit messages.
- [ ] **Commits are frequent and incremental** - showing a clear development history, not a single bulk upload at the end.

### 5b. Branching Strategy
- [ ] **Feature branches are used** - each feature/component developed on its own branch.
- [ ] **Branches are merged into `main`** via pull requests (or at least documented merges).
- [ ] **GitHub's commit graph** shows a visible branching and merging history (professor says "I look at this graph").
- [ ] **All team members have committed** - the Git log must show contributions from multiple people.

### 5c. Project Management Evidence
- [ ] **Use GitHub Issues or GitHub Projects** to track work items / tasks.
- [ ] **Issues reference commits** - ("closes #X" in commit messages links the commit to the issue).
- [ ] **Sprint-based or milestone-based planning visible** - show at least weekly progress updates or milestones.
- [ ] **All team members are visible as contributors** in the project management tool.
- [ ] **Clear division of labor marked** - each group member's specific area of responsibility must be clearly documented in the README or final report.

---

## 6. Documentation, Testing & PR

### 6a. Unit Tests (CMake `make test`)
- [ ] **Unit tests exist for each major class** (not just integration tests).
- [ ] **`CMakeLists.txt` has `enable_testing()` and `add_subdirectory(tests)`.**
- [ ] **Running `make test` from the build directory executes all tests automatically.**
- [ ] **Tests are meaningful** - they send known inputs and verify expected outputs (e.g., send fake pulse counts to `FlowMeter`, verify `getVolumeML()` returns the correct value).
- [ ] **(Optional, high marks):** Use **Google Test (`gtest`)** framework for structured, industry-standard unit tests.
- [ ] **Test coverage includes:** `FlowMeter`, `PumpController`, `FillingController` state machine transitions, `Timer` callback firing.

### 6b. README / Installation Documentation
- [ ] **Prerequisites listed** - exact `apt-get install` commands needed (e.g., `libgpiodcxx`, `cmake`).
- [ ] **Build instructions** - exact `cmake .. && make` commands.
- [ ] **`make test` instructions** - how to run unit tests.
- [ ] **Bill of Materials (BoM) under £75** - list every hardware component with cost and explicitly verify the total is under the £75 budget limit.
- [ ] **Hardware wiring diagram** - circuit diagram or clear wiring table ( partial - README has wiring tables, add a proper circuit diagram image).
- [ ] **Installation on fresh Raspberry Pi** - step-by-step from a blank Pi to running system.
- [ ] **Timing requirements documented** (see 4a - this overlaps with real-time criterion).

### 6c. Code-Level Documentation
- [ ] **All public class members documented** - every public method, callback, and data member has a comment explaining its purpose, parameters, and return value.
- [ ] **(Recommended):** Use **Doxygen-compatible comment syntax** (`/** @brief ... @param ... @return ... */`) so documentation can be auto-generated.
- [ ] **Callback signatures documented** - explain exactly what each callback delivers and when it fires.
- [ ] **Design decisions documented** - the `docs/decisions.md` (already exists ) should explain SOLID choices, thread design decisions, and any trade-offs.

### 6d. UML / Architecture Diagrams
- [ ] **UML class diagram** showing all classes and their relationships (inheritance, composition, dependencies).
- [ ] **Timing/sequence diagram** showing the temporal flow of events (e.g., cup detected → gesture event → state machine → pump on → flow meter pulses → pump off).
- [ ] **System architecture diagram** showing how hardware components connect to software classes.
- [ ] Include these diagrams in the README or a dedicated `docs/architecture.md`.

### 6e. PR / Social Media & Open Source
- [ ] **Demo video** - a short YouTube/video clip showing the system working end-to-end.
- [ ] **Project logo/branding** (professor highlighted the Brew Genie team for this).
- [ ] **(Stretch):** Technical blog post or write-up (professor mentioned RS Design Spark article).
- [ ] Link any social/PR content from the README.
- [ ] **Project Licensing** - ensure your repository has an open-source license file (e.g., MIT, GPL), as it's evaluated under the Promotion criteria.

---

## Deal-Breakers (Automatic Fail / Zero for That Criterion)

> These will kill your grade. Verify **none** of these apply.

- [ ]  **Not using C++** - the project MUST be C++.  (already C++)
- [ ]  **Program becomes unresponsive** under normal operation - e.g., UI freezes during processing.
- [ ]  **`sleep()`/`wait()` used for timing** instead of event-driven architecture.
- [ ]  **Single massive polling loop** (Arduino `loop()` style).
- [ ]  **Global variables** used anywhere.
- [ ]  **`void*` pointers or `malloc()`** anywhere in the code.
- [ ]  **No revision control history** - only one commit at the very end.
- [ ]  **Only one team member committing** - all members must have visible contributions.
- [ ]  **Trivial project scope** - minimal code, mostly PR fluff (not a concern for AquaFlow, but worth confirming sufficient code depth).
- [ ]  **Not plotting values on screen** - technical requirements explicitly state the system must measure values AND *plot them*.
- [ ]  **No mouse interaction** - technical requirements explicitly state the UI must allow *mouse interaction* to change parameters.
- [ ]  **Not running as a standalone embedded app** - the system MUST boot up automatically as a standalone application on the Raspberry Pi without manual terminal interference.

---

## Quick-Wins (Highest ROI, Easiest to Miss)

These are the things the professor explicitly says teams consistently skip and "earn a straight fail" for:

1. ** Write the timing requirements down** - literally one paragraph in the README stating response times.
2. ** Improve commit messages** - run through your Git log and ensure no "updated file" messages exist.
3. ** Run `make test`** - ensure tests execute cleanly from a fresh build.
4. ** Add a UML diagram** - even a simple hand-drawn one photographed and uploaded.
5. ** Record a demo video** - even a 60-second phone recording of the dispenser working.

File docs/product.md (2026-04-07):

# Product Requirements & Plan

This document serves as the master plan for what we are building with the AquaFlow water dispenser project.

## Core Objective
Have the pump, water flow sensor, gesture sensor (APDS-9960), and LCD all working together in our water dispenser (Note: the ultrasonic sensor has been removed in favor of a simpler, gesture-sensor-only hardware layout). The system should use the pump to automatically draw water from a bottle into a cup.

## Target Audience / Setting
- Designed for a restaurant setting (e.g., McDonald's or KFC).
- Key feature: Touchless interaction (hygienic, COVID-friendly approach similar to non-touch doors).

## Interaction Models
We have two approaches for the user interaction via the gesture sensor (APDS-9960):
1. **Fixed Volume / Cup Sizes:** 
   Assign three different gestures for fixed cup sizes (Small, Medium, Large).
2. **Direct Pour Control:** 
   Use gestures to control the start and stop of water pouring directly.

## Smart Hardware Layout & Workflow
The gesture sensor (APDS-9960) acts as a physical **Cup Detector**: When the user slides the cup onto the platform, the cup will sit right in front of the sensor. The sensor's proximity reading will immediately spike, telling your Raspberry Pi, "A cup is parked here, we are safe to pour!"

**Protection from Water:**  
We mount it horizontally on the back wall so it faces the cup natively, protecting the module from water splashes and condensation.

**Intuitive Swiping:**  
The user waves their hand in the hollow bay area (Left, Up, Right) to select their size when there is no cup present, and then places the cup in to start the flow.

### How the Touchless Workflow Operates (No Ultrasonic Needed)
With the pump submerged in the reservoir and the APDS-9960 mounted on the back wall, the system operates as follows:

1. **Idle State:** The APDS is scanning for gestures.
2. **User Approaches:** The user swipes Right. The Pi logs that the user selected a Large (500ml) drink. This selection appears on the LCD screen. Placing the cup closer acts as physical confirmation that this is what the user wants.
3. **Cup Placement:** The user places their cup on the platform. The APDS proximity reading jumps above a certain threshold (e.g., > 150).
4. **Dispense:** The Pi triggers the JT80SL Pump via the `PumpController`. The pump pushes water up the tube.
5. **Monitor:** The Flow sensor spins and counts milliliters.
6. **Stop:** Once the target volume (e.g., 500ml) is reached, the Pi instantly cuts power to the pump. *Note: If the proximity reading drops before the target volume is reached (meaning the user pulled the cup out early), the Pi acts as an emergency stop and instantly shuts off the pump to save the floor from a puddle.*

This creates a brilliant, bulletproof touchless system using the absolute minimum amount of hardware.

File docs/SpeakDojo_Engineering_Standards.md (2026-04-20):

# SpeakDojo Engineering Standards (Rigor Edition)

Version: 1.0  
Owner: SpeakDojo engineering team  
Goal: Ship fast with AI-assisted TypeScript while maintaining reliability and quality standards stricter than the embedded `project_checklist`.

---

## 1. Engineering Constitution (Non-Negotiable Rules)

These rules are hard gates. If any rule fails, the change does not merge.

1. Type safety is mandatory.
   - TypeScript `strict` mode enabled.
   - `noUncheckedIndexedAccess`, `exactOptionalPropertyTypes`, `noImplicitOverride`, `noFallthroughCasesInSwitch` enabled.
   - No `any` in app code.
   - Exception: adapter boundary files only, with comment `// justified-any: <reason>`.
   - Why: type holes become production bugs when speed increases.

2. Runtime validation at all trust boundaries.
   - Every inbound external payload (HTTP request body, query params, webhooks, queue messages, local storage) validated with schema (`zod` or equivalent).
   - Response payloads to clients also validated for critical endpoints.
   - Why: TypeScript protects compile-time assumptions, not runtime input.

3. Mandatory CI quality gates on every PR.
   - `lint`, `typecheck`, `unit`, `integration`, `e2e-smoke`, `security-scan`, `dependency-audit` must pass.
   - No direct pushes to `main`.
   - Minimum 1 review for low-risk PR, 2 reviews for high-risk PR.
   - Why: rigor must be automated to scale with fast iteration.

4. Production bug policy.
   - Every confirmed bug requires a regression test before fix merge.
   - Incident postmortem required for Sev-1/Sev-2 incidents.
   - Why: each bug is a process failure signal, not only a code failure.

5. Explicit performance and reliability budgets.
   - Critical API p95 latency budget defined and enforced.
   - Error-rate and uptime SLOs defined and tracked.
   - Why: if not measured, quality silently decays.

6. AI-generated code policy.
   - AI output is draft code, never trusted code.
   - Human reviewer must verify correctness, security, edge cases, and tests.
   - Why: velocity without verification increases hidden defect rate.

---

## 2. Quality Bar (Stricter Than Embedded Checklist)

The embedded checklist is excellent for hardware and RT constraints. SpeakDojo goes further by enforcing operational and product-level rigor:

1. Embedded style rigor:
   - deterministic behavior expectations
   - strict interfaces
   - explicit failure handling

2. Added web/service rigor:
   - strong schema validation at runtime
   - service-level objectives (SLOs) and error budgets
   - security gates and dependency governance
   - incident response and postmortem process
   - progressive rollout with feature flags and rollback plans

Practical definition: a feature is not "done" until it is safe to operate in production, not just correct on a laptop.

---

## 3. Definition of Done (Feature-Level Gate)

A feature can be merged only if all boxes are true:

1. Spec written (short but explicit).
   - Problem statement
   - Inputs/outputs
   - Edge cases
   - Failure modes

2. Types and schemas complete.
   - No `any` introduced.
   - Request/response schemas implemented.

3. Tests complete.
   - Unit tests for domain logic.
   - Integration tests for DB/network boundaries.
   - At least one e2e scenario for user-visible behavior.
   - Regression test for any bug fixed during feature work.

4. Observability complete.
   - Structured logs for key events.
   - Metrics added for key outcomes and failure modes.
   - Trace spans for critical path where applicable.

5. Operational safety complete.
   - Feature flag or staged rollout defined for risky changes.
   - Rollback procedure documented in PR.
   - Migration plan and rollback for schema/data changes.

6. Review quality complete.
   - PR description includes "what", "why", "risk", "test evidence".
   - Reviewer checklist fully answered.

---

## 4. Required Code Standards (TypeScript + Architecture)

1. Layered architecture.
   - Domain layer: pure logic, no framework imports.
   - Application layer: orchestrates use-cases.
   - Infrastructure layer: DB/API adapters.
   - UI layer: rendering and interaction only.
   - Why: testability and change isolation.

2. Dependency rule.
   - Inner layers never depend on outer layers.
   - Why: prevents framework lock-in and tangled coupling.

3. Domain logic purity.
   - Business rules in pure functions where possible.
   - Side-effects isolated.
   - Why: easier testing and lower bug surface.

4. Error handling.
   - No silent catch blocks.
   - Expected failures returned as typed results.
   - Unexpected failures logged with correlation IDs.
   - Why: silent failures create ghost bugs.

5. API contracts.
   - API versioning strategy required for breaking changes.
   - Contract tests for public API endpoints.
   - Why: preserves backward compatibility.

6. Naming and readability.
   - Names must explain intent, not implementation detail.
   - Functions should be small and single-purpose.
   - Why: readability is long-term speed.

---

## 5. Testing Standards (Minimums)

1. Coverage thresholds.
   - Global: 85% line, 80% branch.
   - Critical modules (payments, auth, entitlements, streak engine): 95% line, 90% branch.
   - Why: high-risk code needs higher confidence.

2. Mutation testing.
   - Run mutation tests on critical domain modules.
   - Mutation score target: >= 70%.
   - Why: catches weak tests that only exercise happy paths.

3. Test pyramid enforcement.
   - Unit tests: many, fast.
   - Integration tests: moderate.
   - E2E tests: focused, critical journeys only.
   - Why: speed and confidence balance.

4. Deterministic test execution.
   - No test depends on wall-clock time or random seed without control.
   - Use fake timers for time logic.
   - Why: flaky tests destroy trust in CI.

5. Contract and migration tests.
   - DB migrations must have forward and rollback checks.
   - External API contracts pinned and tested.
   - Why: most production failures happen at boundaries.

---

## 6. Reliability and SRE Standards

1. SLOs (initial recommendation).
   - API availability: 99.9% monthly.
   - Critical endpoint p95 latency: < 300 ms.
   - Background job success rate: >= 99.5%.
   - Why: SLOs turn quality goals into objective decisions.

2. Error budgets.
   - If error budget burn > 2x normal rate, freeze feature work for stabilization.
   - Why: prevents shipping velocity from outrunning system health.

3. Runbooks.
   - Required for auth outage, payment outage, data corruption scenario.
   - Why: execution speed under pressure depends on pre-written playbooks.

4. Incident management.
   - Sev-1 response time target: <= 15 minutes.
   - Postmortem template required with corrective action owners and deadlines.
   - Why: rigor includes response quality, not only prevention.

---

## 7. Security Standards

1. Secure defaults.
   - Least privilege for DB and cloud credentials.
   - Secrets never in source control.
   - Why: credential leaks are high-impact failures.

2. Dependency governance.
   - Automated vulnerability scan per PR.
   - Critical CVEs block merge unless explicit security waiver.
   - Why: supply chain risk is continuous.

3. Auth and session controls.
   - Enforce secure cookies, CSRF protection, and token expiry/rotation where relevant.
   - Why: auth weaknesses are common breach vectors.

4. Input and output hardening.
   - Validate and sanitize all user input.
   - Escape output where required by render context.
   - Why: prevents injection classes of vulnerabilities.

---

## 8. Data Integrity and Migration Standards

1. Migration discipline.
   - Every schema migration has backward compatibility strategy.
   - Destructive migrations must be two-phase.
   - Why: protects uptime and rollback capability.

2. Idempotency for critical writes.
   - Payment, enrollment, entitlement, and progress updates must be idempotent.
   - Why: retries are normal in distributed systems.

3. Auditability.
   - Critical user-impacting changes (entitlements, billing state) must be audit logged.
   - Why: enables debugging, trust, and compliance readiness.

---

## 9. Frontend Standards (If SpeakDojo Has Web UI)

1. Accessibility.
   - WCAG 2.2 AA target for key pages.
   - Keyboard navigation and focus states mandatory.
   - Why: accessibility is quality, not decoration.

2. Performance.
   - Core Web Vitals budget set per route.
   - Bundle size budgets with CI alerts.
   - Why: slow UI harms learning outcomes and retention.

3. State management rigor.
   - Server state and UI state separated.
   - Avoid hidden mutable shared state.
   - Why: state bugs are subtle and expensive.

---

## 10. AI-Assisted Development Rules

1. Prompt discipline.
   - Prompt includes constraints: architecture layer, tests required, no `any`, failure paths.
   - Why: quality of generated code follows clarity of constraints.

2. Verification loop.
   - Generate -> inspect -> test -> harden -> re-test.
   - Why: one-pass generation is not engineering.

3. Human accountability.
   - Reviewer signs off that generated code matches team standards.
   - Why: accountability cannot be outsourced.

---

## 11. PR Template (Required Sections)

Every PR must include:

1. What changed.
2. Why it changed.
3. Risk assessment (low/medium/high) and why.
4. Test evidence (commands and outputs summary).
5. Observability updates (logs/metrics/traces).
6. Rollback plan.
7. Screenshots or recordings for UI changes.

PRs missing any section are not reviewed.

---

## 12. SpeakDojo Domain-Specific Standards

1. Streak and schedule correctness.
   - Timezone-safe logic with tests for DST and day boundaries.
   - Why: learning apps are time-sensitive by design.

2. Lesson progress integrity.
   - Progress writes idempotent and monotonic where expected.
   - Why: user trust collapses if progress disappears or rewinds.

3. Payment and entitlement safety.
   - Payment success must not grant duplicate entitlements.
   - Payment retry must not double-charge.
   - Why: billing defects are high-severity trust failures.

4. AI feedback safeguards.
   - Prompt/response logging for moderation and debugging.
   - Safety checks for generated content.
   - Why: AI quality and safety must be observable.

---

## 13. Weekly Engineering Rituals

1. Weekly stability review (30 min).
   - Top errors, SLO burn, flaky tests, slow endpoints.

2. Weekly architecture review (30 min).
   - Identify coupling creep and shortcut debt.

3. Weekly bug taxonomy review.
   - Classify root causes and install process safeguards.

Why: rigor decays without cadence.

---

## 14. Metrics Dashboard (Minimum)

Track and review weekly:

1. Change failure rate.
2. Mean time to recovery (MTTR).
3. CI pass rate and flaky test rate.
4. Escaped defects per release.
5. p95 latency and error rate for critical routes.
6. Dependency vulnerability backlog.

Why: high standards require measurable feedback loops.

---

## 15. Reading List for Deep Rigor (Books + Why)

1. Code Complete (Steve McConnell)
   - Why: practical engineering discipline and construction best practices.

2. Clean Architecture (Robert C. Martin)
   - Why: long-term maintainability and dependency direction.

3. Designing Data-Intensive Applications (Martin Kleppmann)
   - Why: correctness, consistency, replication, idempotency, and system tradeoffs.

4. Accelerate (Nicole Forsgren, Jez Humble, Gene Kim)
   - Why: evidence-based practices for speed with reliability.

5. Site Reliability Engineering (Google SRE book)
   - Why: SLOs, error budgets, operations discipline.

6. The DevOps Handbook (Gene Kim et al.)
   - Why: flow, feedback loops, and production-safe delivery.

7. Practical Monitoring (Mike Julian)
   - Why: observability that supports debugging and confidence.

8. Web Application Security (Andrew Hoffman)
   - Why: practical threat-driven security approach for web products.

9. Refactoring (Martin Fowler)
   - Why: safely improving design as the codebase evolves.

10. Working Effectively with Legacy Code (Michael Feathers)
   - Why: safe change strategies when speed meets existing complexity.

---

## 16. Keep-This-In-Mind Coding Heuristics

When coding fast, pause and ask:

1. What assumption could break in production?
2. What happens on retries, duplicates, and timeouts?
3. What invariant must always remain true?
4. How will I detect failure quickly if this goes wrong?
5. Can I roll this back safely within minutes?

If you cannot answer these clearly, the feature is not production-ready yet.

---

## 17. Adoption Plan (First 2 Weeks)

Week 1:

1. Turn on strict TS flags and lint rules.
2. Add required CI gates.
3. Add PR template and enforce branch protections.
4. Define initial SLOs for top 3 critical endpoints.

Week 2:

1. Add runtime schemas for all external API boundaries.
2. Add e2e smoke tests for top 3 user journeys.
3. Add incident runbooks for auth and payment failures.
4. Instrument logs/metrics for critical paths.

This gives immediate rigor without blocking product velocity for months.

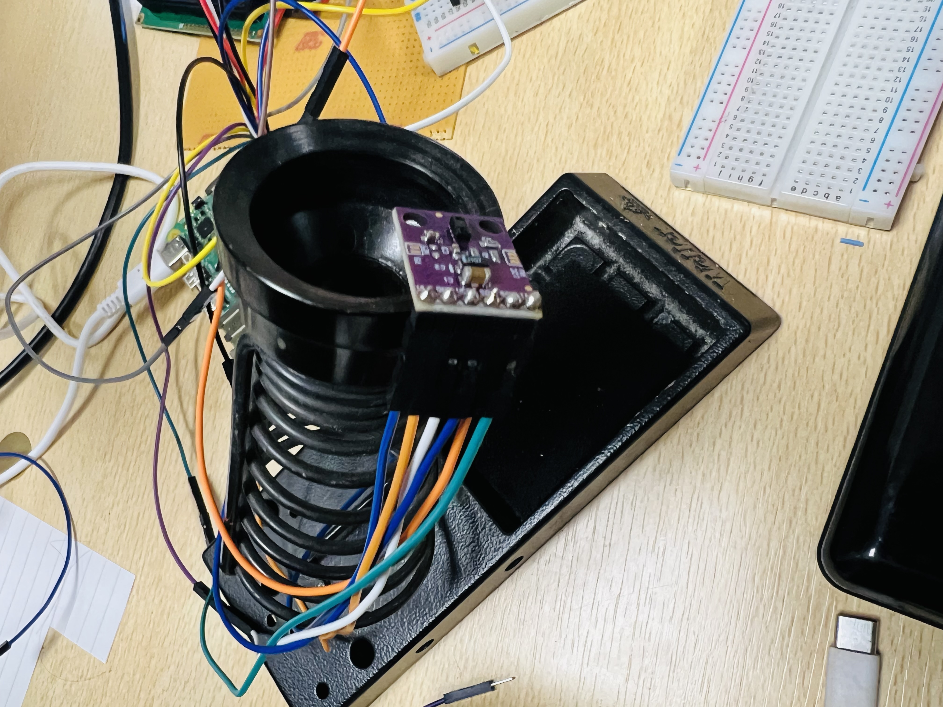
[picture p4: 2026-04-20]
images/gest2.jpeg

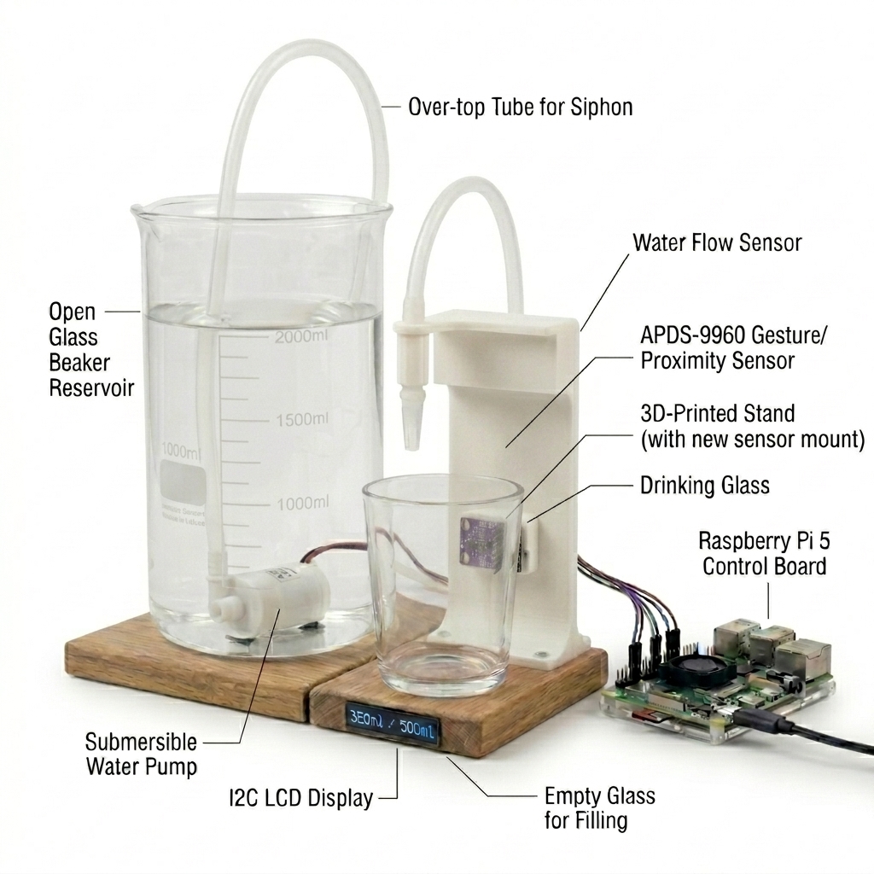
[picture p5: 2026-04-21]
images/physical_layout_gesture.png

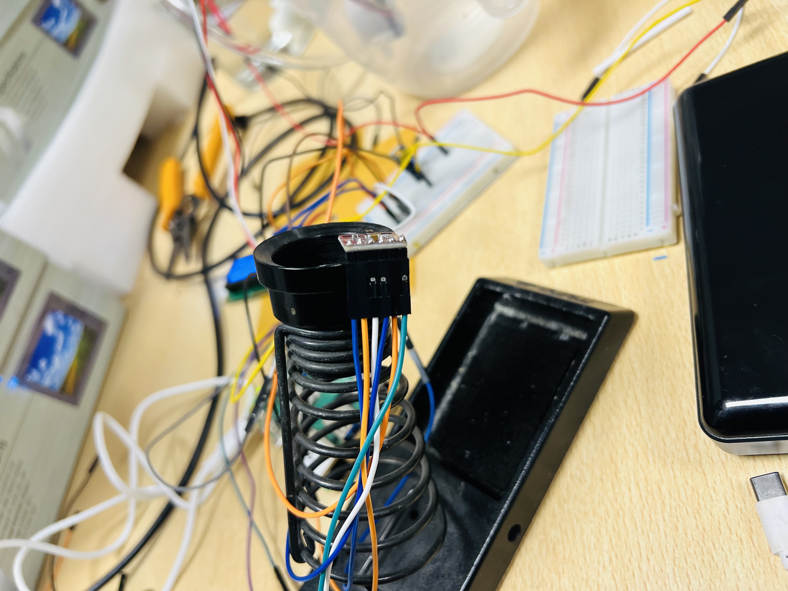
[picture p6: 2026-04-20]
images/gest1.jpeg

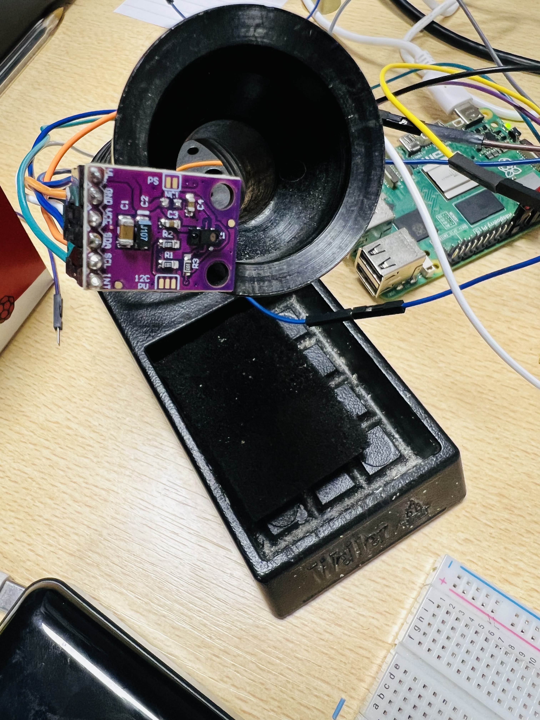
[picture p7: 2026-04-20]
images/gest3.jpeg

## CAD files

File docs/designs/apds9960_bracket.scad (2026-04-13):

// ============================================================
// AquaFlow — APDS-9960 Gesture Sensor Wall-Mount Bracket
// ============================================================
// The APDS-9960 board is 15.5mm wide x 20.5mm tall.
// This bracket clips it flush against the back wall of the
// dispenser, facing outward into the cup bay.
//
// HOW TO USE:
//   Press F5 to preview. Press F6 to fully render.
//   File → Export → Export as STL when done.
// ============================================================


// --- Board Dimensions (do not change) ---
board_w   = 15.5;   // APDS board width  (mm)
board_h   = 20.5;   // APDS board height (mm)
board_thk = 1.6;    // standard PCB thickness

// --- Bracket Parameters (adjust to taste) ---
wall_thk   = 2.5;   // bracket wall thickness
lip_depth  = 2.0;   // how far the lip grips the board edge
lip_height = 3.0;   // height of the retaining lips

// --- Mounting screw holes (M3) ---
screw_d    = 3.2;   // M3 clearance hole
screw_head = 6.0;   // M3 countersink diameter
screw_off  = 4.0;   // distance from corner to screw centre

// --- Derived outer dimensions ---
outer_w = board_w + (wall_thk * 2);
outer_h = board_h + (wall_thk * 2);

// ============================================================
// Main bracket body
// ============================================================
difference() {
    union() {
        // Base plate (the part that screws to the back wall)
        cube([outer_w, wall_thk, outer_h]);

        // Left retaining lip (grips left edge of PCB)
        translate([0, wall_thk, wall_thk])
            cube([wall_thk, lip_depth, board_h]);

        // Right retaining lip (grips right edge of PCB)
        translate([outer_w - wall_thk, wall_thk, wall_thk])
            cube([wall_thk, lip_depth, board_h]);

        // Bottom retaining lip (keeps board from sliding down)
        translate([0, wall_thk, 0])
            cube([outer_w, lip_depth, wall_thk]);

        // Top retaining lip (locks board in completely)
        translate([0, wall_thk, outer_h - wall_thk])
            cube([outer_w, lip_depth, wall_thk]);
    }

    // --- Sensor window: hollow cutout so the sensor faces forward ---
    // Slightly smaller than the board so the sensor chip peeks through
    translate([wall_thk + 2, -1, wall_thk + 2])
        cube([board_w - 4, wall_thk + 2, board_h - 4]);

    // --- Mounting screw holes in the base plate ---
    // Bottom-left
    translate([screw_off, wall_thk / 2, screw_off])
        rotate([90, 0, 0]) cylinder(d = screw_d, h = wall_thk + 1, $fn = 30);

    // Bottom-right
    translate([outer_w - screw_off, wall_thk / 2, screw_off])
        rotate([90, 0, 0]) cylinder(d = screw_d, h = wall_thk + 1, $fn = 30);

    // Top-left
    translate([screw_off, wall_thk / 2, outer_h - screw_off])
        rotate([90, 0, 0]) cylinder(d = screw_d, h = wall_thk + 1, $fn = 30);

    // Top-right
    translate([outer_w - screw_off, wall_thk / 2, outer_h - screw_off])
        rotate([90, 0, 0]) cylinder(d = screw_d, h = wall_thk + 1, $fn = 30);
}

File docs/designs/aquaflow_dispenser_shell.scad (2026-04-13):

// ============================================================
//  AquaFlow — Full Dispenser Shell  v1.0
// ============================================================
//
//  Build footprint:  220 × 200 × 250 mm  (W × D × H)
//  Bambu P1S limit:  256 × 256 × 256 mm  ✓  FITS
//
//  LAYOUT (top-view, Y axis = front-to-back)
//  ┌──────────────────────────────┐ ← rear wall (Y = 200)
//  │   Electronics Bay  (73 mm)  │   Pi, wiring, flow sensor
//  ├──────────────────────────────┤ ← partition wall (Y = 120)
//  │      Cup Bay  (120 mm)      │   pump tube drops in from top
//  └──────────────────────────────┘ ← front face (Y = 0)
//    open to user → cup slides in
//
//  FRONT FACE (Z axis = bottom-to-top)
//  ┌──────────────────┐  ← top wall
//  │    LCD window    │  at Z ≈ 220 mm
//  │                  │
//  │                  │
//  │   CUP BAY OPEN   │  Z = 3.5 → 203.5 mm (200 mm tall)
//  │                  │
//  └──────────────────┘  ← floor
//
//  HOW TO USE:
//    F5  = fast preview (orange, good for layout checks)
//    F6  = full render  (grey, export-ready)
//    File → Export → Export as STL
//
//  PRINT SETTINGS (recommended for James Watt South Bambu P1S):
//    Material:      PLA
//    Layer height:  0.2 mm
//    Infill:        20–25 % gyroid
//    Walls:         3 perimeters
//    Supports:      REQUIRED — cup bay leaves a large overhang
//    Estimated time: 16–22 h
//    Estimated mass: ~500 g
// ============================================================


// ============================================================
//  PARAMETERS  ← edit these to tune the build
// ============================================================

/* [Shell] */
body_w  = 220;      // outer width  (mm)
body_d  = 200;      // outer depth, front‑to‑back (mm)
body_h  = 250;      // outer height (mm)
wall    = 3.5;      // shell wall thickness (mm)

/* [Cup Bay — opened from front face] */
// Standard large McDonald's / KFC cup: ~107 mm top dia, ~180 mm tall
bay_w   = 150;      // bay width  (cups to ~115 mm dia with clearance)
bay_d   = 120;      // bay depth, front face → partition wall
bay_h   = 205;      // bay height (5 mm clearance over a 200 mm cup)
// NOTE: bay opens fully at front face and from the floor up to bay_h

/* [Nozzle / Tube Port] */
// 6 mm silicone tube, 1 mm wall clearance each side → 8 mm hole
tube_od = 8;
// Port is centred in X over the cup bay, emerges through the top wall
// The water tube routes from the electronics bay, up and over the partition

/* [LCD Window — 1602‑style, 16 × 2 chars] */
// Visible display area of a standard 1602 LCD: ~72 mm × 25 mm
lcd_w        = 74;  // window width  (add 2 mm tolerance)
lcd_h        = 27;  // window height (add 2 mm tolerance)
lcd_gap_above_bay = 12; // solid wall between top of cup bay and LCD bottom

/* [APDS‑9960 Gesture Sensor — board 15.5 × 20.5 mm] */
// Mounted flush in partition wall, facing the cup bay (toward front)
sns_brd_w   = 15.5; // actual board width
sns_brd_h   = 20.5; // actual board height
sns_tol     = 1.5;  // press‑fit tolerance each side
sns_pocket_w = sns_brd_w + sns_tol * 2; // = 18.5 mm
sns_pocket_h = sns_brd_h + sns_tol * 2; // = 23.5 mm
sns_pocket_d = 2.5; // pocket depth (PCB sits 2.5 mm into wall, chip faces forward)
sns_window   = 9;   // square through‑hole for sensor chip line‑of‑sight
// Sensor sits at 35 % of bay height — good cup‑detection height
sns_z_pct    = 0.35;

/* [YF‑S401 Flow Sensor mounting channel — 58 × 35 × 27 mm body] */
// The flow sensor sits inline in the water tube inside the electronics bay.
// A clip rail is printed on the electronics bay floor to locate it.
fs_w = 60;  // rail slot width  (sensor body 58 mm + 2 mm clearance)
fs_h = 10;  // clip rail height

/* [Raspberry Pi — standard mounting hole pattern Pi 2/3/4] */
// Hole‑to‑hole distances: 58 mm (X) × 49 mm (Y)
pi_hole_d  = 2.7;   // M2.5 clearance diameter
pi_x_span  = 58;    // mounting hole X span
pi_y_span  = 49;    // mounting hole Y span
pi_post_d  = 7;     // pillar outer diameter
pi_post_h  = 6;     // pillar height (PCB standoff)
// Pi centred in electronics bay width; 12 mm behind partition wall
// Electronics bay: Y = (bay_d + wall)  to  Y = (body_d − wall)
//   depth = 200 − 3.5 − 123.5 = 73 mm  → Pi Y‑span 49 mm + 12 + some margin ✓

/* [Rear Inlet — external reservoir/pump tube entry] */
// The JT80SL pump sits submerged in an external water bottle/reservoir.
// The outlet tube enters the rear wall of the dispenser here.
inlet_d = 10;   // tube entry hole (6 mm tube, generous clearance)
inlet_z = 25;   // height from base floor (near bottom, below electronics)

/* [Rear Access Panel] */
// A large opening in the back wall for wiring, Pi access, flow sensor, etc.
// A matching cut‑out cover plate can be printed separately.
access_border = 18; // solid border kept around the access panel

/* [Rubber Feet] */
foot_d   = 14;  // diameter
foot_h   = 7;   // height (elevates shell, protects countertop)
foot_off = 18;  // inset from corner


// ============================================================
//  DERIVED VALUES  (do not edit)
// ============================================================

inner_w = body_w - wall * 2;
inner_d = body_d - wall * 2;

// Cup bay left/right edges (centred in X)
bay_x0  = (body_w - bay_w) / 2;

// LCD window position
lcd_z0  = wall + bay_h + lcd_gap_above_bay;
lcd_x0  = (body_w - lcd_w) / 2;

// Sensor position on partition wall
sns_z0  = wall + bay_h * sns_z_pct;
sns_x0  = (body_w - sns_pocket_w) / 2;

// Pi mounting posts — centred in width, 12 mm behind partition
pi_x0   = (body_w - pi_x_span) / 2;
pi_y0   = bay_d + wall + 12;

// Flow sensor clip rail: centred in width, on electronics bay floor
fs_x0   = (body_w - fs_w) / 2;
fs_y0   = bay_d + wall + 5;


// ============================================================
//  MODULES
// ============================================================

// --- 1. Outer shell: all four walls + floor, open top -------------
module shell() {
    difference() {
        cube([body_w, body_d, body_h]);
        // Hollow interior
        translate([wall, wall, wall])
            cube([inner_w, inner_d, body_h]);
    }
}

// --- 2. Partition wall: separates cup bay from electronics bay ----
module partition_wall() {
    translate([wall, bay_d, wall])
        cube([inner_w, wall, body_h - 2 * wall]);
}

// --- 3. Wire/tube pass-through at the top of the partition --------
//   16 mm wide × 35 mm tall slot so the water tube and signal
//   wires can cross from the electronics bay into the cup bay.
module partition_passthrough() {
    translate([body_w / 2 - 8, bay_d - 0.5, wall + bay_h - 35])
        cube([16, wall + 1, 35]);
}

// --- 4. Cup bay void: hollows out the front section ---------------
module cup_bay_void() {
    // Removes: front wall (Y 0→bay_d) and interior bay space
    // Leaves floor (Z starts at wall), leaves side walls of bay
    translate([bay_x0, 0, wall])
        cube([bay_w, bay_d, bay_h]);
}

// --- 5. LCD window: through‑hole in front wall, above cup bay -----
module lcd_window() {
    translate([lcd_x0, -1, lcd_z0])
        cube([lcd_w, wall + 2, lcd_h]);
}

// --- 6. Nozzle port: tube exits top of shell above cup bay --------
//   Water falls from this port down into the waiting cup.
module nozzle_port() {
    translate([body_w / 2, bay_d / 2, body_h - 0.5])
        cylinder(d = tube_od, h = wall + 1, $fn = 30);
}

// --- 7. Sensor pocket in partition wall (PCB press‑fit) -----------
module sensor_recess() {
    // a) PCB pocket: board is pressed from the cup‑bay side
    translate([sns_x0, bay_d - sns_pocket_d, sns_z0])
        cube([sns_pocket_w, sns_pocket_d + 0.5, sns_pocket_h]);

    // b) Sensor through‑window: centred in the pocket, passes fully
    //    through the partition wall so the sensor chip can see the cup
    translate([
        body_w / 2 - sns_window / 2,
        bay_d - wall - 0.5,
        sns_z0 + (sns_pocket_h - sns_window) / 2
    ])
        cube([sns_window, wall + 1, sns_window]);
}

// --- 8. Rear access panel ----------------------------------------
//   Large opening in back wall. Keep access_border of solid wall.
module rear_access() {
    translate([
        access_border,
        body_d - 0.5,
        access_border
    ])
        cube([
            body_w - access_border * 2,
            wall + 1,
            body_h - access_border * 2
        ]);
}

// --- 9. Rear tube inlet: external reservoir hose entry hole -------
module rear_tube_inlet() {
    translate([body_w / 2, body_d - 0.5, inlet_z])
        rotate([90, 0, 0])
            cylinder(d = inlet_d, h = wall + 1, $fn = 30);
}
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

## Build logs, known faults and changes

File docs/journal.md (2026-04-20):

# Developer Journal

A chronological log of work done in the lab, daily goals, and simple tasks.

---

## 20 March 2026
**Time:** 14:16
**Location:** Rankine Lab 509

**Goals:**
- Identify the correct water pump and replace the solenoid valve setup.
- Figure out how to safely connect the pump to the Raspberry Pi.
- Resolve 5V power distribution across the various sensors and the pump.

**Notes:**
- We decided to switch back from the 12V Solenoid valve to a submersible pump because the solenoid was bulky and not performing as expected with the relay setup.
- Explored powering the pump. Tried direct pi connection (Bad Idea). Explored 3x 1.5v AA batteries (didn't go this route). Ultimately wired a T1P121 transistor with a flyback diode and a 1000 ohm resistor. 

---

## [Date TBD] 
**Time:** 11:23
**Location:** RTES lab

**Tasks:**
- [x] Connect the gesture sensor and have it working. (Read APDS-9960 specs at 11:26)
- [ ] Make a social media plan. We need to upload 5 times and get people to like.
- [ ] Research about the 3D printing.

**11:33 Subtask:**
- [ ] Find out how to connect the gesture sensor to the Raspberry Pi.

**Notes & Observations:**
- The wires we use are quite short and in some cases the connections are weak.
- Right now this is no big deal because we are testing our connections separately, but this will become important when we are bringing the product together.

---

## 14 April 2026

**Single Responsibility Review and Refactors**

### PumpController
- Responsibility: owns pump GPIO lifecycle and ON/OFF actuation.
- SRP decision: PASS.
- Changes made:
  - Replaced direct `std::cout` and `std::cerr` calls with `Logger::info()` and `Logger::error()`.
  - Replaced internal static relay flag with constructor-injected `DriveMode` (`RELAY_ACTIVE_LOW` or `TRANSISTOR_ACTIVE_HIGH`).
  - Default mode is `TRANSISTOR_ACTIVE_HIGH` to preserve current behaviour.

### FlowMeter
- Responsibility: detects flow pulses, debounces hardware noise, and converts pulses to millilitres.
- SRP decision: PASS.
- Changes made:
  - Removed `hasReachedTarget()` from `FlowMeter` to avoid business-rule leakage.
  - Kept `FlowMeter` as a measurement driver exposing `getPulseCount()` and `getVolumeML()` only.
  - Moved target-comparison logic into controllers/callers.

### LcdDisplay
- Responsibility: low-level 16x2 LCD rendering over I2C.
- SRP decision: PASS.
- Changes made:
  - Removed business-formatting methods (`showVolume()` and `showStatus()`).
  - Moved row text construction (`Vol:`, `Bottles:`) to `main.cpp` orchestrator logic.
  - Routed LCD init/shutdown logs through `Logger`.
  - Kept shutdown as hardware-only (backlight off and fd close); farewell text is now composed by caller before shutdown.

### GestureSensor
- Responsibility: read APDS9960 registers and emit proximity/gesture events.
- SRP decision: PASS.
- Changes made:
  - Replaced direct warning output with `Logger::warn()` for unknown device ID path.

### Monitor
- Responsibility: format and log state updates and transitions.
- SRP decision: PASS.
- Changes made:
  - Removed unused `registerCallback` API and internal callback member (YAGNI cleanup).
  - Assumed full responsibility for format and emission of human-readable state transition logs, making `FillingController` independent of UI/logging.

### FillingController
- Responsibility: Orchestrate hardware components for the filling cycle.
- SRP decision: PASS.
- Changes made:
  - Removed all `Logger` dependencies. All transition logs are deferred to `Monitor` for ultra-pure SRP.

### Final SRP Outcome
- All core classes now have one clear reason to change.
- Business rules and UI text formatting are kept in orchestration/presentation layers, not in hardware drivers.

### Open/Closed Principle Review (14 April 2026)
- `IHardwareDevice` remains the lifecycle extension point (`init()` and `shutdown()`), and `PumpController`, `FlowMeter`, `GestureSensor`, and `LcdDisplay` extend it without modifying the base class.
- Added role interfaces: `IProximitySensor`, `IPump`, and `IFlowMeter`.
- Refactored `FillingController` to depend only on those abstractions, not concrete hardware drivers.
- Evidence added: updated class diagram and hierarchy documentation in `docs/architecture.md`.
- Verdict: OCP/DIP pass at both hardware and orchestration layers.

---

**Time:** 17:31
**Location:** Local workspace / Codex review pass

**Goals:**
- Improve the code in ways that are directly supported by the RTES course material.
- Strengthen encapsulation and unit-testing quality without weakening the event-driven runtime design.
- Bring hardware-driver logging into line with the documented SRP decisions.

**Tasks Completed:**
- [x] Removed `#define private public` from the unit tests.
- [x] Added test-only seams behind `AQUAFLOW_TESTING` so tests can inject safe synthetic state without touching private members.
- [x] Reworked `FlowMeterTest`, `FillingControllerTest`, and `PumpControllerTest` to avoid real hardware initialisation.
- [x] Removed the real-time `sleep_for()` delay from `FillingControllerTest`.
- [x] Routed remaining hardware-driver console output through `Logger`.
- [x] Added null-safe handling in `PumpController` so unit-test simulation mode does not dereference a missing GPIO request.
- [x] Enabled `AQUAFLOW_TESTING` only for the `filling_tests` target in CMake.

**Notes & Rationale:**
- The main driver for these changes was the course requirement around **encapsulation**. The checklist says top-band work should expose a clear public interface with data accessed through getters, setters, or callbacks only. Our previous tests were violating this by redefining `private` as `public` and directly mutating internal fields like `pulseCount_` and `eventCallback_`.
- To fix this without weakening the production design, we added **test-only seams** guarded by `#ifdef AQUAFLOW_TESTING`. This means the real application binary keeps its original encapsulation, while the unit tests get small, explicit hooks for simulation.
- `FlowMeter` now has `injectPulseCountForTest(int)` so the test can verify volume calculations and target detection without touching private atomics directly.
- `GestureSensor` now has `emitEventForTest(const GestureEvent&)` so the controller tests can simulate proximity events through a method instead of reaching into the stored callback function.
- `FillingController` now has `forceHoldElapsedForTest(double)` so we can fast-forward the confirmation phase in tests without sleeping for 2.1 seconds. This makes the tests deterministic and avoids time-based flakiness.
- `PumpController` now has `enableSimulationForTest()` so the pump tests can check logical ON/OFF behaviour without requiring `/dev/gpiochip...` to exist. We also wrapped `request_->set_value(...)` in null checks so simulation mode is safe.
- These changes are course-backed because the marking material explicitly values **unit testing**, **encapsulation**, and **safe data access**, and our previous tests were undermining that story even though the production architecture was strong.

**Logger / SRP Cleanup:**
- `GestureSensor.cpp` was still using `std::cerr` directly for the unknown APDS-9960 device ID warning.
- `LcdDisplay.cpp` was still using `std::cout` / `std::cerr` directly for init/shutdown messages.
- We replaced those direct console writes with `Logger::warn`, `Logger::info`, and `Logger::error` so the hardware drivers remain focused on hardware responsibilities only.
- This matches the ADR decision that hardware-driver output should be routed through `Logger` to better respect **Single Responsibility Principle (SRP)** and keep console formatting/thread-safe output centralized.

**Files Changed:**
- `src/hardware/FlowMeter.h`
- `src/hardware/FlowMeter.cpp`
- `src/hardware/GestureSensor.h`
- `src/hardware/GestureSensor.cpp`
- `src/hardware/LcdDisplay.cpp`
- `src/hardware/PumpController.h`
- `src/hardware/PumpController.cpp`
- `src/state/FillingController.h`
- `src/state/FillingController.cpp`
- `tests/FlowMeterTest.cpp`
- `tests/FillingControllerTest.cpp`
- `tests/PumpControllerTest.cpp`
- `tests/CMakeLists.txt`

**Outcome:**
- The runtime architecture is still event-driven: `FlowMeter` still waits on GPIO edge events and `GestureSensor` still uses timerfd-based blocking behavior.
- The unit tests are now much closer to true unit tests instead of semi-integration tests.
- The project documentation and the actual code are now more consistent with each other, especially around encapsulation, SRP, and testability.

**Limitations / Follow-up:**
- I could not run `cmake` in the current shell because `cmake` was not installed or not available on `PATH`, so the build/test pass still needs to be verified in a configured development environment.
- A sensible next improvement would be to harden `GestureSensor::init()` so failure paths are more transactional and leave the object in a cleaner state if setup fails partway through.

---

## 20 April 2026
**Location:** Lab / Remote (SSH)

### Interaction Model Redesign
- Deprecated gesture-based cup size selection (unreliable in practice).
- Switched to a **button-driven model**: short press (`b`) cycles Small → Medium → Large; long press / `s` confirms selection.
- Proximity sensor (APDS-9960) is now used solely as a **cup presence trigger** — it fires the fill once the cup is held within ~10 cm for 1.5 seconds (confirmation hold).

### Proximity Sensor Fix
- Root cause of cup-not-detected bug: `GestureSensor::init()` was enabling the gesture engine (`GEN=1`, `GMODE=1`), which intercepts proximity events and prevents `PDATA` from updating.
- Fix: stripped all gesture-engine registers from `init()`. Now configures `PON=1, PEN=1` only — identical to the working Python verification test.
- Threshold calibrated to **90** (PDATA units) corresponding to ~10 cm detection distance with the McDonald's UK medium cup (ambient = 5–16, at 10 cm = 94–112, saturation at < 2 cm = 255).

### Flow Meter Calibration — Important Reference
> **Always use `sudo ./calibrate` in the build directory to recalibrate. Do not rely on Python/lgpio for pulse counting — lgpio callbacks do not work on the Pi 5 without the lgpiod daemon. The C++ driver uses libgpiod edge detection which works correctly.**

| Date | Pulses | Actual Volume | ML_PER_PULSE |
|---|---|---|---|
| 2026-04-02 | 2711 | 200 ml | 0.073774 |
| 2026-04-20 (incorrect) | — | 250 ml (estimated) | 0.1651 ← **wrong** |
| **2026-04-20 (final)** | **4027** | **260 ml (measured)** | **0.064564** ← use this |

- The `0.1651` value was causing the pump to stop after dispensing only ~97 ml when targeting 250 ml.
- The correct value `0.064564` was confirmed by the `./calibrate` C++ tool: 4027 pulses physically corresponded to 260 ml in a measuring jug.

### Cumulative Fill
- System now resumes a fill from the last dispensed volume if the cup is removed mid-fill and replaced.
- Flow meter resets **only** when a new size is confirmed (long press), not on cup removal/replacement.

### Hardware Notes
- GPIO 18 (pump) floats HIGH before the app claims it — pump can auto-start when powerbank is connected. Fix: add 10 kΩ pull-down resistor between GPIO 18 and GND, or add `gpio=18=op,dl` to `/boot/firmware/config.txt`.
- LCD I2C transport faults (`[ERROR] LcdDisplay transport fault`) were caused by writing to the LCD every 100 ms tick. Fixed by only updating LCD on state changes.

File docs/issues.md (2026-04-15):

# Project Issue Tracker (Offline)

This document tracks technical issues and milestones for the AquaFlow project. 
*Note: These are synced to GitHub Issues periodically.*

## Demo Configuration

> **Liquid:** Pepsi
> **Cups:** McDonald's standard soft-drink cups
> - Small  → 250 ml
> - Medium → 400 ml
> - Large  → 500 ml
>
> These volumes are already configured in `PinConfig.h` as `CUP_SMALL_ML`, `CUP_MEDIUM_ML`, and `CUP_LARGE_ML`.

---

## Open Issues

### [#19] Volume Calibration: McDonald's Cup Sizes + LCD Validation
- **Status:** Open
- **Priority:** Critical
- **Labels:** `calibration`, `hardware`, `lcd`
- **Description:** The current volume targets (`CUP_SMALL_ML=250`, `CUP_MEDIUM_ML=400`, `CUP_LARGE_ML=500`) are based on nominal McDonald's UK cup specs, not measured Pepsi fill levels. Real-world accuracy depends on the flow meter's `ML_PER_PULSE` calibration and actual cup capacity under normal fill conditions.
- **Tasks to complete:**
  - [ ] Measure the actual usable volume of each McDonald's cup size (Small / Medium / Large) with Pepsi.
  - [ ] Run a dispense test for each size, weigh or measure the dispensed liquid, and adjust `CUP_SMALL_ML`, `CUP_MEDIUM_ML`, `CUP_LARGE_ML` in `include/PinConfig.h` accordingly.
  - [ ] Re-verify `ML_PER_PULSE` calibration constant — current value is `0.073774` ml/pulse (measured 2026-04-02 with water; Pepsi may behave slightly differently due to density/viscosity).
  - [ ] Confirm the LCD second row shows the correct target ml for each size and that the live fill progress accurately reflects the dispensed volume.

---

### [#20] 3D Printing: Enclosure and Mounting Design
- **Status:** Open
- **Priority:** High
- **Labels:** `hardware`, `mechanical`, `design`
- **Description:** The system currently has no physical enclosure or mounting structure. All hardware components — the Raspberry Pi 5, pump reservoir, flow meter, LCD display, and APDS-9960 sensor — need to be mounted in a unified, stable, and visually presentable housing suitable for a demo.
- **Design requirements:**
  - [ ] Reservoir mount to hold the Pepsi bottle/container above the pump.
  - [ ] Sensor bay aligned at cup-top height for reliable proximity detection (~5–10 cm range).
  - [ ] Secure bracket for the LCD1602 display, facing the user.
  - [ ] Cable management channels for I2C, GPIO, and power wires.
  - [ ] Dispense nozzle guide to direct water flow accurately into McDonald's cups.
  - [ ] Raspberry Pi 5 mounting with ventilation clearance.
- **Tools:** CAD software (e.g., Fusion 360 / FreeCAD / Tinkercad); 3D printer (PLA recommended).

---

### [#16] APDS9960: Gestures not detected & Proximity range degraded in C++ port
- **Status:** Open
- **Priority:** Critical
- **Labels:** `bug`, `hardware`
- **Description:** After porting from the Adafruit CircuitPython APDS9960 library to our custom C++ driver, gesture detection has stopped working and proximity range has dropped from ~20 cm to ~2–5 cm. Seven root causes identified via comparison with the reference Python library — see [`docs/github_issue_apds9960_draft.md`](github_issue_apds9960_draft.md) for full analysis and proposed fix.

---

### [#15] Finalise Unit Testing for FillingController
- **Status:** Open
- **Priority:** High
- **Description:** Need to verify state transitions in `FillingController` using a Mock FlowMeter.

### [#18] Safety Enhancement: Distinguish Cup Presence from Empty Hand Waves
- **Status:** Open
- **Priority:** High
- **Labels:** `enhancement`, `safety`
- **Description:** Currently, the APDS-9960 sensor serves as both the proximity trigger (cup detector) and the gesture detector. If a user waves their hand rapidly across the empty sensor, the hand itself triggers proximity (`bottlePresent_` = true) and registers a gesture, causing the pump to briefly turn on before the hand exits and triggers the safety abort. We need to implement a stricter safety condition (e.g., integrating a dedicated IR/Ultrasonic cup sensor, or requiring the proximity signal to be completely static for *N* seconds before accepting gestures) to mathematically guarantee that water never flows unless a physical cup is definitively present.

---

## Closed Issues

### [#17] Unit Test Compilation Failure (libgpiod mock API divergence)
- **Status:** Closed
- **Description:** `make -j4` failed when compiling `filling_tests` because `src/hardware/FlowMeter.cpp` was built against a mock version of `gpiod.hpp` (`tests/mock_include/gpiod.hpp`) that did not fully match the real `libgpiod` v2 C++ bindings on the Raspberry Pi 5. Specifically, the mock lacked the `set_bias` method, missing `bias` enumerations, and the correct `add_line_settings()` overload for single integers. It also caused an ambiguous resolution for the edge event `type()` method.
- **Resolved:** Fixed `mock_include/gpiod.hpp` to perfectly emulate the real `libgpiod` v2 API used by the system hardware. This allowed both the hardware integration targets and the unit test framework (`filling_tests`) to compile identically against the same `FlowMeter.cpp` logic.

### [#14] Replace std::cout with Logger in state machine
- **Status:** Closed (Linked in commit 9e1f565)
- **Resolved:** Removed non-deterministic I/O from `FillingController::tick()`.

### [#13] Implement acquire/release memory ordering for proximity flag
- **Status:** Closed (Linked in commit 9e1f565)
- **Resolved:** Improved thread safety for the `bottlePresent_` atomic.

### [#12] Fix GestureSensor POLL_INTERVAL
- **Status:** Closed (Linked in commit 10d415f)
- **Resolved:** Reverted to 50ms for better responsiveness.

### [#11] Add timerfd-based blocking to GestureSensor
- **Status:** Closed
- **Resolved:** Replaced `sleep_for` with kernel-managed timerfd.

### [#10] Migrate Pump to libgpiod v2.x
- **Status:** Closed
- **Resolved:** Updated hardware drivers for Raspberry Pi 5 compatibility.

### [#1] Initial Project Structure
- **Status:** Closed
- **Resolved:** Created hardware, state, and monitor directories.

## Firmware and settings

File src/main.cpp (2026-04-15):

#include "PinConfig.h"
#include "app/AquaFlowApp.h"
#include "hardware/GestureSensor.h"
#include "hardware/PumpController.h"
#include "hardware/FlowMeter.h"
#include "hardware/LcdDisplay.h"
#include "utils/Logger.h"

#include <csignal>
#include <signal.h>

// ─────────────────────────────────────────────────────────────────────────────

int main() {
    // ── Construct hardware drivers ────────────────────────────────────────────
    GestureSensor    gestureSensor(GESTURE_I2C_BUS, GESTURE_I2C_ADDR, GESTURE_THRESHOLD);
    PumpController   pump(GPIO_CHIP_NO, PUMP_PIN);
    FlowMeter        flowMeter(GPIO_CHIP_NO, FLOW_PIN, static_cast<float>(ML_PER_PULSE));
    LcdDisplay       lcd(LCD_I2C_BUS, LCD_I2C_ADDRESS);

    // ── Application Orchestration ─────────────────────────────────────────────
    AquaFlowApp app(gestureSensor, pump, flowMeter, lcd);

    // ── Initialise hardware ───────────────────────────────────────────────────
    if (!gestureSensor.init()) {
        Logger::error("Failed to initialise GestureSensor");
        return 1;
    }
    if (!pump.init()) {
        Logger::error("Failed to initialise PumpController");
        gestureSensor.shutdown();
        return 1;
    }
    if (!flowMeter.init()) {
        Logger::error("Failed to initialise FlowMeter");
        pump.shutdown();
        gestureSensor.shutdown();
        return 1;
    }
    if (!lcd.init()) {
        Logger::error("Failed to initialise LcdDisplay — continuing without display");
    }
    
    Logger::info("=== AquaFlow Filling Machine Started ===");
    Logger::info("Mode          : Button-select + Proximity-trigger");
    Logger::info("Sizes         : Small=250 ml  Medium=400 ml  Large=500 ml");
    Logger::info("Controls      : 'b'=cycle size   's'=select   Ctrl+C=quit");
    Logger::info("Proximity     : I2C bus " + std::to_string(GESTURE_I2C_BUS) + ", addr 0x39, threshold=" + std::to_string(GESTURE_THRESHOLD));

    app.start();

    // ── Block main thread until SIGINT (Ctrl+C) via sigwait ──────────────────
    sigset_t sigset;
    sigemptyset(&sigset);
    sigaddset(&sigset, SIGINT);
    sigaddset(&sigset, SIGTERM);
    pthread_sigmask(SIG_BLOCK, &sigset, nullptr);

    int sig = 0;
    sigwait(&sigset, &sig);
    Logger::info("Signal " + std::to_string(sig) + " received — shutting down.");

    // ── Shutdown ─────────────────────────────────────────────────────────────
    app.shutdown();

    lcd.shutdown();
    flowMeter.shutdown();
    pump.shutdown();
    gestureSensor.shutdown();

    Logger::info("AquaFlow stopped. Goodbye.");
    return 0;
}

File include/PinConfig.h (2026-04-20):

#ifndef PINCONFIG_H
#define PINCONFIG_H

// ─── GPIO Pin Assignments (BCM numbering) ────────────────────────────────────

// DC Water Pump (via TIP122 transistor)
constexpr int PUMP_PIN = 18;   // GPIO18 (BCM)

// YF-S401 Flow Meter
// Wiring: Red→Pin2(5V)  Black→Pin9(GND)  Yellow→Pin11(GPIO17)
// Signal is open-collector; internal pull-up enabled in FlowMeter::setupGpio()
constexpr int FLOW_PIN = 17;   // GPIO17 — BCM17 — Physical Pin 11

// Push-Button (short press = cycle size, long press = select)
// Physical button: GPIO26, Physical Pin 37.  Not yet installed.
// Keyboard simulation over SSH: 'b' = cycle size,  's' = select.
constexpr int BUTTON_PIN = 26;

// ─── Timing Settings ─────────────────────────────────────────────────────────
// State-machine tick rate.  Keep at 100 ms for stable proximity polling.
constexpr int LOOP_INTERVAL_MS = 100;   // ms

// Cup confirmation hold time — cup must remain in range this long before the
// pump starts.  Prevents false triggers while the user is still placing the cup.
// NOTE: 800ms was too fast during testing — the cup trigger fired mid-placement.
//       Increased to 1500ms (1.5s) to give the user time to set the cup down stably.
//       Adjust if the wait feels too long in production.
constexpr int CUP_CONFIRM_MS = 1500;  // ms

// ─── Flow Settings ───────────────────────────────────────────────────────────
// YF-S401 spec: ~5880 pulses/litre  →  1000 mL / 5880 pulses ≈ 0.1701 mL/pulse
//
// CALIBRATION HISTORY:
//   2026-04-02: 2711 pulses for 200 ml actual → 0.073774 ml/pulse
//   2026-04-20: System reported 111.7 ml when ~250 ml was actually dispensed.
//               Correction factor = 250 / 111.7 = 2.238
//               New value = 0.073774 × 2.238 = 0.1651 ml/pulse  ← INCORRECT
//   2026-04-20: Calibration tool (./calibrate) measured 4027 pulses for 260 ml actual.
//               New value = 260 / 4027 = 0.064561 ml/pulse
//               Previous 0.1651 was causing under-fill (~97 ml for a 250 ml target).
//
// To re-calibrate: run sudo ./calibrate in the build directory.
// Let the pump fill a known volume, press Ctrl+C, enter the actual ml.
constexpr double ML_PER_PULSE = 0.064564;  // mL per pulse — calibrated 2026-04-20 (tool: 4027 pulses = 260 ml)

// ─── Cup Size Volumes (McDonald's UK dispensing targets) ─────────────────────
constexpr double CUP_SMALL_ML  = 250.0;   // Small  (~8.5 fl oz)
constexpr double CUP_MEDIUM_ML = 400.0;   // Medium (~14.1 fl oz)
constexpr double CUP_LARGE_ML  = 500.0;   // Large  (~17.6 fl oz)

// Legacy alias — kept for test-file compatibility
constexpr double TARGET_VOLUME_ML = CUP_MEDIUM_ML;

// ─── GPIO Chip ───────────────────────────────────────────────────────────────
// /dev/gpiochip4 for Raspberry Pi 5; use 0 for Pi 1–4.
constexpr unsigned int GPIO_CHIP_NO = 4u;

// ─── I2C Bus / Addresses ─────────────────────────────────────────────────────
// APDS-9960: SDA→Pin3 (GPIO2), SCL→Pin5 (GPIO3), VCC→3.3V.  Address fixed 0x39.
constexpr int GESTURE_I2C_BUS  = 1;      // /dev/i2c-1
constexpr int GESTURE_I2C_ADDR = 0x39;   // APDS-9960 fixed I2C address

// Proximity threshold (0–255).
// CALIBRATED 2026-04-15 against McDonald's UK medium cup at 10 cm distance:
//   Ambient (no object)  :   5 – 16
//   Cup at exactly 10 cm :  94 – 112  (average 103)
//   Cup closer than 10 cm: 112 – 255
//
// Threshold set to 90 (slightly below the 10 cm floor of 94) to give a small
// margin for cup angle/reflectivity variation while still reliably excluding
// objects further than 10 cm.
//
// To re-calibrate: run tests/gesture_direct_test.py and note PDATA at your
// target distance, then set this to ~10% below that minimum reading.
constexpr int GESTURE_THRESHOLD = 90;

// LCD1602 with PCF8574T I2C backpack
constexpr int LCD_I2C_BUS     = 1;
constexpr int LCD_I2C_ADDRESS = 0x27;

#endif // PINCONFIG_H

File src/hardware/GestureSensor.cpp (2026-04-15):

#include "hardware/GestureSensor.h"
#include <array>
#include <linux/i2c-dev.h>
#include <sys/ioctl.h>
#include <sys/timerfd.h>
#include <fcntl.h>
#include <unistd.h>
#include <thread>
#include <cstring>
#include <cmath>
#include <stdexcept>
#include <sstream>
#include <chrono>

#include "utils/Logger.h"

// ── APDS-9960 Register Map ──────────────────────────────────────────────────
// Ported from Adafruit_APDS9960.h (v1.3.1, BSD licence)
#define APDS9960_ENABLE   0x80
#define APDS9960_ATIME    0x81
#define APDS9960_CONTROL  0x8F
#define APDS9960_ID       0x92
#define APDS9960_STATUS   0x93
#define APDS9960_PDATA    0x9C
#define APDS9960_GPENTH   0xA0
#define APDS9960_GEXTH    0xA1
#define APDS9960_GCONF1   0xA2
#define APDS9960_GCONF2   0xA3
#define APDS9960_GPULSE   0xA6
#define APDS9960_PPULSE   0x8E
#define APDS9960_GCONF3   0xAA
#define APDS9960_GCONF4   0xAB
#define APDS9960_GFLVL    0xAE
#define APDS9960_GSTATUS  0xAF
#define APDS9960_AICLEAR  0xE7
#define APDS9960_GFIFO_U  0xFC

// Device ID (Adafruit library checks for 0xAB only; we additionally accept
// the alternate Adafruit silicon revision 0xA8 and the DollaTek clone 0x9E)
#define BRAND_ID_ADAFRUIT_1 0xAB
#define BRAND_ID_ADAFRUIT_2 0xA8
#define BRAND_ID_DOLLATEK   0x9E

// Gesture direction codes (matching Adafruit library)
#define GESTURE_UP    0x01
#define GESTURE_DOWN  0x02
#define GESTURE_LEFT  0x03
#define GESTURE_RIGHT 0x04

const int POLL_INTERVAL_MS = 50;

// ── Helper: milliseconds since epoch (replaces Arduino millis()) ─────────────
static uint64_t nowMs() {
    return static_cast<uint64_t>(
        std::chrono::duration_cast<std::chrono::milliseconds>(
            std::chrono::steady_clock::now().time_since_epoch()).count());
}

// ─────────────────────────────────────────────────────────────────────────────

GestureSensor::GestureSensor(int i2cBus, int i2cAddr, int threshold)
    : i2cBus_(i2cBus), i2cAddr_(i2cAddr), threshold_(threshold) {}

GestureSensor::~GestureSensor() {
    shutdown();
}

// ── init() — Ported from Adafruit_APDS9960::begin() ─────────────────────────
// This follows the exact same register configuration sequence as the Adafruit
// Arduino library (v1.3.1), adapted for Linux I2C.
// Reference: Adafruit_APDS9960_Library-1.3.1/Adafruit_APDS9960.cpp, lines 90-137
bool GestureSensor::init() {
    if (running_) return true;

    try {
        const std::string devPath = "/dev/i2c-" + std::to_string(i2cBus_);
        fd_ = open(devPath.c_str(), O_RDWR);
        if (fd_ < 0) {
            throw std::runtime_error("Cannot open " + devPath + ": " + strerror(errno));
        }

        if (ioctl(fd_, I2C_SLAVE, i2cAddr_) < 0) {
            throw std::runtime_error("ioctl I2C_SLAVE failed: " + std::string(strerror(errno)));
        }

        // ── Verify device ID ─────────────────────────────────────────────────
        uint8_t id = readRegister(APDS9960_ID);
        if (id != BRAND_ID_ADAFRUIT_1 && id != BRAND_ID_ADAFRUIT_2 && id != BRAND_ID_DOLLATEK) {
            std::ostringstream msg;
            msg << "Warning: Unknown APDS9960 device ID: 0x" << std::hex << static_cast<int>(id);
            Logger::warn(msg.str());
        }

        // ── Adafruit begin() sequence ────────────────────────────────────────
        // Step 1: Set default integration time (10ms) and ADC gain (4x)
        // ATIME = 256 - (10 / 2.78) = 256 - 3 = 253
        writeRegister(APDS9960_ATIME, 253);
        // CONTROL: AGAIN=4x (0x01), PGAIN=4x (0x0C), LDRIVE=100mA (0x00)
        // Adafruit default: CONTROL = 0x01 (AGAIN=4x only); add PGAIN=4x for better
        // proximity sensitivity at range.
        writeRegister(APDS9960_CONTROL, 0x0D);  // PGAIN=4x (bits 3:2=11), AGAIN=4x (bits 1:0=01)

        // PPULSE: proximity IR pulse count and length — feeds the PDATA register.
        // This is SEPARATE from GPULSE (gesture engine). Without this, the proximity
        // engine runs at power-on default (1 pulse, 4 us) which gives PDATA < 5 at
        // any practical distance, making threshold=40 unreachable.
        // Adafruit default: PPLEN=1 (8 us), PPULSE=9 (10 pulses) -> 0x89
        writeRegister(APDS9960_PPULSE, 0x89);

        // Step 2: Disable all engines to start clean
        // ENABLE: GEN=0, PEN=0, AEN=0, PON=0  (everything off)
        writeRegister(APDS9960_ENABLE, 0x00);

        // Step 3: Clear interrupts
        // Write to AICLEAR register (command-only, clears all non-gesture interrupts)
        {
            uint8_t reg = APDS9960_AICLEAR;
            if (::write(fd_, &reg, 1) != 1) {
                Logger::warn("Failed to clear APDS9960 interrupts");
            }
        }

        // Step 4: Power cycle — disable then re-enable with delays
        // (Adafruit: enable(false); delay(10); enable(true); delay(10);)
        // NOTE: These are hardware-mandated I2C device settling delays during
        // one-time initialisation, NOT real-time timing mechanisms. The APDS-9960
        // datasheet requires >= 5.7 ms power-on stabilisation time.
        writeRegister(APDS9960_ENABLE, 0x00);  // PON=0
        std::this_thread::sleep_for(std::chrono::milliseconds(10));
        writeRegister(APDS9960_ENABLE, 0x01);  // PON=1
        std::this_thread::sleep_for(std::chrono::milliseconds(10));

        // ── Proximity-only configuration ──────────────────────────────────────
        // The gesture engine (GEN) is intentionally NOT enabled here.
        // When GEN=1 the sensor captures proximity events and enters gesture
        // mode whenever PDATA > GPENTH, preventing PDATA from updating normally.
        // Since the new design uses proximity-only detection, we mirror the
        // exact register sequence used by the working Python verification test:
        //   bus.write_byte_data(ADDR, 0x80, 0x05)  # PON + PEN
        //
        // PPULSE: 8 µs pulse length, 10 pulses — gives good range without
        // saturating at cup distances (~5-10 cm).
        writeRegister(APDS9960_PPULSE, 0x89);

        // CONTROL: PGAIN=4x (bits 3:2 = 11), AGAIN=4x (bits 1:0 = 01)
        writeRegister(APDS9960_CONTROL, 0x0D);

        // ENABLE: PON=1, PEN=1 only — no gesture engine, no ALS
        writeRegister(APDS9960_ENABLE, 0x00);  // power off
        std::this_thread::sleep_for(std::chrono::milliseconds(10));
        writeRegister(APDS9960_ENABLE, 0x05);  // PON=1, PEN=1
        std::this_thread::sleep_for(std::chrono::milliseconds(10));

        Logger::info("GestureSensor: proximity-only mode (threshold=" +
                     std::to_string(threshold_) + "), PDATA register polling active.");
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

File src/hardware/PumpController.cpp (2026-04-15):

#include "hardware/PumpController.h"

#include <stdexcept>
#include "utils/Logger.h"

// ─────────────────────────────────────────────────────────────────────────────

PumpController::PumpController(unsigned int chipNo, unsigned int pumpPin, DriveMode mode)
    : chipNo_(chipNo), pumpPin_(pumpPin), mode_(mode) {}

PumpController::~PumpController() {
    shutdown();
}

// ── IHardwareDevice ───────────────────────────────────────────────────────────

bool PumpController::init() {
    if (initialised_) return true;

    try {
        const std::string chipPath = "/dev/gpiochip" + std::to_string(chipNo_);
        chip_ = std::make_shared<gpiod::chip>(chipPath);

        // Configure the pump pin as output, idle = pump OFF
        gpiod::line_config lineCfg;
        lineCfg.add_line_settings(
            pumpPin_,
            gpiod::line_settings()
                .set_direction(gpiod::line::direction::OUTPUT)
                .set_output_value(offValue()));   // start de energised

        auto builder = chip_->prepare_request();
        builder.set_consumer("pump_controller");
        builder.set_line_config(lineCfg);
        request_ = std::make_shared<gpiod::line_request>(builder.do_request());

        running_     = false;
        initialised_ = true;

        Logger::info("PumpController initialised via libgpiod (chip=" +
                     std::to_string(chipNo_) + ", pin=" + std::to_string(pumpPin_) +
                     ", mode=" + std::string((mode_ == DriveMode::RELAY_ACTIVE_LOW) ? "RELAY(active-LOW)" : "TRANSISTOR(active-HIGH)") +
                     ")");
        return true;

    } catch (const std::exception& e) {
        Logger::error("PumpController::init() error: " + std::string(e.what()));
        return false;
    }
}

void PumpController::shutdown() {
    if (!initialised_) return;
    // Ensure pump is off before releasing GPIO
    if (request_) {
        request_->set_value(pumpPin_, offValue());
    }
    running_     = false;
    initialised_ = false;
    request_.reset();
    chip_.reset();
    Logger::info("PumpController shut down (pump OFF).");
}

// ── Pump control ──────────────────────────────────────────────────────────────

void PumpController::turnOn() {
    if (!initialised_ || running_) return;
    if (request_) {
        request_->set_value(pumpPin_, onValue());
    }
    running_ = true;
    Logger::info("Pump started!");
}

void PumpController::turnOff() {
    if (!initialised_ || !running_) return;
    if (request_) {
        request_->set_value(pumpPin_, offValue());
    }
    running_ = false;
    Logger::info("Pump stopped.");
}

bool PumpController::isRunning() const { return running_; }

#ifdef AQUAFLOW_TESTING
void PumpController::enableSimulationForTest() {
    initialised_ = true;
    running_ = false;
    request_.reset();
    chip_.reset();
}
#endif

// ── Helpers ───────────────────────────────────────────────────────────────────

gpiod::line::value PumpController::onValue() const {
    // Relay (active-LOW): energise coil by pulling LOW
    // Transistor (active-HIGH): switch ON by pulling HIGH
    return (mode_ == DriveMode::RELAY_ACTIVE_LOW) ? gpiod::line::value::INACTIVE
                                                  : gpiod::line::value::ACTIVE;
}

gpiod::line::value PumpController::offValue() const {
    return (mode_ == DriveMode::RELAY_ACTIVE_LOW) ? gpiod::line::value::ACTIVE
                                                  : gpiod::line::value::INACTIVE;
}

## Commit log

2026-03-14 Rewrite FlowSensor & UltrasonicSensor with gpiod.hpp, add mock GPIO tests
2026-03-18 Documentation file that explain the project hardware and software. plus water pump controller
2026-03-25 fix: address professor review — remove all sleep commands, migrate pump to libgpiod, replace polling loop
    RTES review fixes:
    - UltrasonicSensor: replace sleep_for(2ms) with one-shot timerfd, replace sleep_for(10us) with clock_nanosleep(CLOCK_MONOTONIC) — both are true kernel sleeps, no busy loops
    - PumpController: fully migrated from lgpio (hobbyist lib) to libgpiod v2 (officially supported), constructor now takes (chipNo, pumpPin) matching other drivers
    - main(): replaced while(running)+sleep_for polling loop with POSIX sigwait() — main thread truly blocks in kernel until SIGINT/SIGTERM, zero CPU polling
    - CMakeLists.txt: removed lgpio linkage from filling_machine (no longer needed)
    -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
    [PinConfig.h, PumpController.cpp, main.cpp]
2026-03-25 feat: migrate pump pin to 18 and set active-HIGH logic based on test results
2026-03-25 test: add pump_integration_test standalone executable to CMake
2026-03-25 fix: libgpiod v2.2 compile error - ambiguous add_line_settings overload
    [FlowMeter.cpp, PumpController.cpp]
2026-03-25 Fix: Resolve call of overloaded 'add_line_settings' is ambiguous
    [PumpController.cpp]
2026-04-02 feat: implement LCD display driver and integration test suite
2026-04-02 feat: add FlowMeter hardware implementation and pin configuration definitions
2026-04-02 feat: add PinConfig header file for hardware pin definitions
2026-04-02 added i2c ultrasonic test sensor script and lcd display explanation
2026-04-02 replaced i2c ultrasonic script with gpio based script using lgpio
    [gpio_ultrasonic.py]
2026-04-02 updated gpio ultrasonic test sensor script with minor timing changes
2026-04-07 feat: implement GestureSensor driver and add project documentation
2026-04-08 feat: implement APDS9960 gesture sensor driver and add integration test for touchless dispensing control
2026-04-08 feat: implement APDS9960 gesture sensor driver and integrate into hardware test suite
2026-04-08 feat: implement APDS9960 gesture sensor driver with proximity and directional swipe detection
2026-04-12 feat: implement GestureSensor hardware driver and add A1 project grading checklist
2026-04-12 refactor: replace UltrasonicSensor with GestureSensor throughout
    The ultrasonic sensor has been removed from the design; cup detection
    is now handled by the APDS-9960 GestureSensor via proximity events.
    Changes:
    - GestureSensor: replace sleep_for(50ms) polling with a timerfd
    blocking read — RTES-compliant, zero CPU between firings.
    timerfd is created in init(), closed in shutdown() to unblock
    the worker thread cleanly. Mirrors the pattern in Timer.cpp.
    - FillingController: take GestureSensor& instead of UltrasonicSensor&.
    Cup detection is now fully event-driven: GestureSensor fires a
    proximity callback which writes to std::atomic<bool> bottlePresent_.
    tick() reads that flag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
    [GestureSensor.cpp, PinConfig.h, main.cpp]
2026-04-13 docs: add architecture decision records, hardware specifications and project assembly checklist with associated 3D design files.
    [apds9960_bracket.scad, aquaflow_dispenser_shell.scad]
2026-04-15 Fix APDS9960: complete gesture/proximity driver rewrite (closes #16)
    - Port Adafruit C++ library init sequence: power cycle, GCONF1/GCONF2/GPULSE/GCONF3/GCONF4
    - GPENTH lowered 50->5, GEXTH set to 30 (CircuitPython defaults) for 20cm range
    - GCONF1=0x82: GFIFOTH=8 datasets, GEXPERS=4 cycles (prevents premature engine exit)
    - GPULSE=0xC9: 10 pulses at 32us (was default 1 pulse/4us, explains range regression)
    - FIFO stale data cleared on init (GFIFO_CLR)
    - GFOV overflow check added before every FIFO read
    - Replaced 4 separate register reads with single burst readBurst() transaction
    - readGesture() now processes ALL datasets per batch (non-blocking adaptation)
    - Removed C-style array; using std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
    [GestureSensor.cpp]
2026-04-15 Fix APDS9960 proximity: add PPULSE and PGAIN to init sequence
    PPULSE (0x8E) was never written, leaving the proximity engine at the
    power-on default of 1 pulse at 4 us. This produced PDATA values below 5
    at any practical distance, making the software threshold of 40 permanently
    unreachable and causing the system to stay in WAITING indefinitely.
    Set PPULSE=0x89 (10 pulses at 8 us, Adafruit default) and PGAIN=4x via
    CONTROL register to restore proximity detection range to approximately 20 cm.
    GPULSE (gesture engine pulse config) is a separate register and was already
    correct.
    [GestureSensor.cpp]
2026-04-15 Fix integration test build failures: link Logger and update LCD test API
    [LcdIntegrationTest.cpp]
2026-04-15 Fix duplicate variable name in LCD test
    [LcdIntegrationTest.cpp]
2026-04-15 Fix FlowMeterTest after removing hasReachedTarget()
2026-04-15 Fix initialization race condition dropping early PROXIMITY_TRIGGERED events
    [main.cpp]
2026-04-15 Fix hysteresis gap for low threshold to allow proximity clear
    [GestureSensor.cpp]
2026-04-15 Redesign: button-cycle size selection + proximity-trigger filling
    [PinConfig.h, main.cpp]
2026-04-15 Fix: log only on state change, remove DIAG spam, add lastVolumeML to Monitor
    [GestureSensor.cpp]
2026-04-15 Fix proximity detection: disable gesture engine in init (GEN=1 was blocking PDATA updates)
    [GestureSensor.cpp]
2026-04-15 Calibrate GESTURE_THRESHOLD=90 for 10cm cup detection (measured avg=103 at 10cm)
2026-04-15 Cumulative fill: only reset flow meter on new size selection, not on cup re-placement
2026-04-15 docs: Add issues #19 (volume calibration) and #20 (3D printing enclosure)
2026-04-20 Fix: remove duplicate 'Pump started!' log from FillingController (PumpController already logs it)
    [gesture_direct_test.py]
2026-04-20 Recalibrate flow meter: ML_PER_PULSE 0.073774→0.1651 (system read 111.7ml for ~250ml actual)
2026-04-20 Add calibrate tool: C++ binary that runs pump until Ctrl+C then calculates ML_PER_PULSE
2026-04-20 Recalibrate ML_PER_PULSE=0.064561 from calibration tool (4027 pulses = 260ml actual)
2026-04-20 Calibration: ML_PER_PULSE=0.064564 (exact tool output, 4027 pulses = 260ml)
2026-04-20 Journal: add 20 April 2026 entry — calibration, proximity fix, cumulative fill, hardware notes
2026-04-20 refactor: rename project to FlowFizzy, reorganize image assets, and update README documentation
